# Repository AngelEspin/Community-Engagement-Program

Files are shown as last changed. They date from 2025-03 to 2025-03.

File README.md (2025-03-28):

# Community-Engagement-Program
This project involves the design and development of didactic prototypes aimed at helping children understand renewable energy concepts, specifically focusing on wind energy. The project includes:

Electronic Design: Design of PCB boards for educational prototypes.

Internal Wiring: Wire modeling using Autodesk Inventor.

Mechanical Design: Proper dimensioning and machining techniques to bring the prototypes to life.

Wind Energy System: The prototype includes a fan and generator to demonstrate wind energy.

The goal of this project is to create hands-on tools for educational purposes, enabling a better understanding of renewable energy systems in an interactive way.

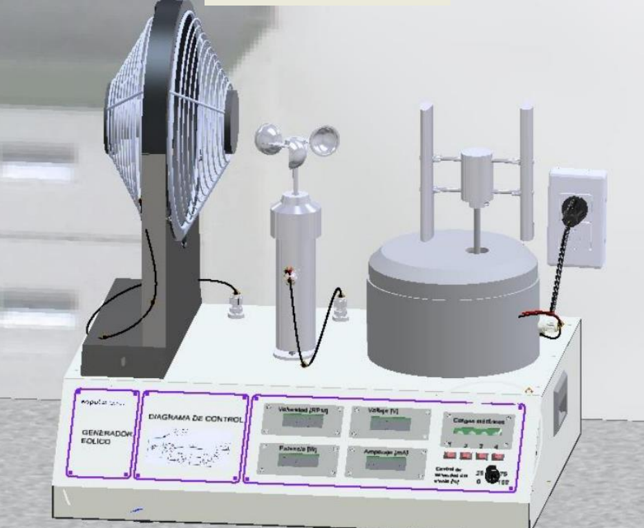
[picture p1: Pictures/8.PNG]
Final

## Mechanical Design
After taking the dimensions of the components into reality by using Inventor we need to specify to the mechanized laboratory exactly how this is supposed to be made, the fan is expected to be build by mechanizing it from a steel block, with the following dimensions:
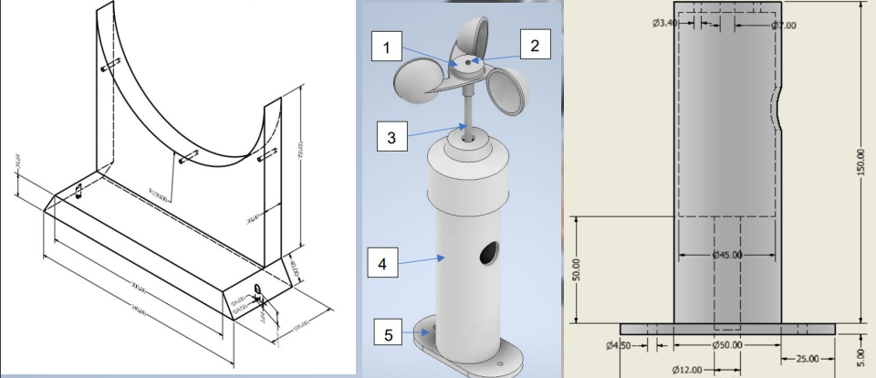
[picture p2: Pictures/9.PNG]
Mecanizado

## PCB's design
The requirements for this didactic module were that it needs to show qualitified and visualized the amount of energy produced by the wind generator. In order to do so, we've created PCB's that contains 7 segments led arrays and little incandescent bulbs by making the corresponding PCB's as shown in:
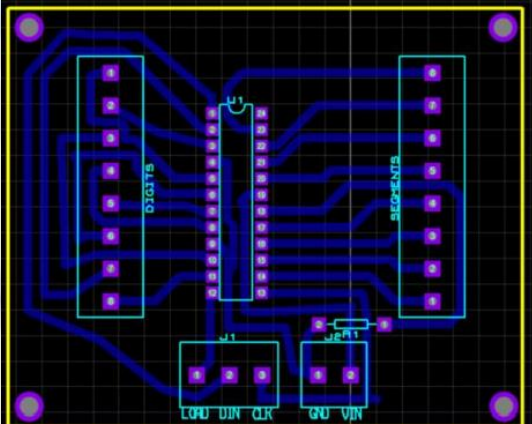
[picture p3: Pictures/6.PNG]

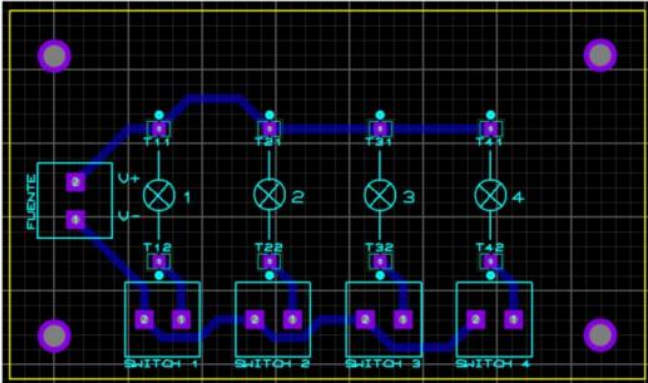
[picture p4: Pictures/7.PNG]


After making the PCB's usign proteus we export this into inventor by using a proteus option, and after verifying that it does fullfil the standards we incorporate this new modules to the existing 3D CAD design
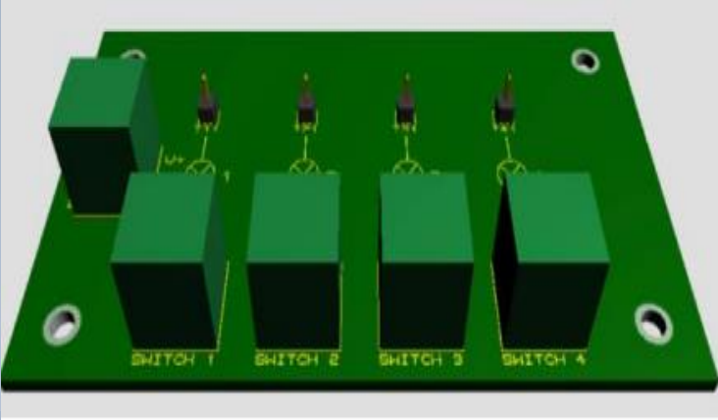
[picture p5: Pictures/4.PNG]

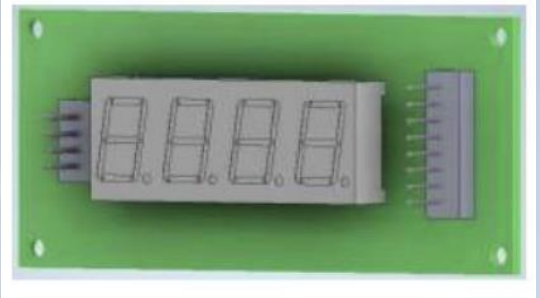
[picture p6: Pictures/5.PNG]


## Connection using Proteus modules and Inventor
After exporting the corresponing PCB's for each of the parts (the luminosity required to show the quantity of the wind energy and the displays showing the exact amount of energy consumed) the next step is to connect this new modules into the existing microcontrollers such as ATmega328P (Arduino Module), after succesfully connecting this components the next part is to make sure that the physical restrictions do not interfere with the connections, since the cables are numbered specifying the current that they can pass.
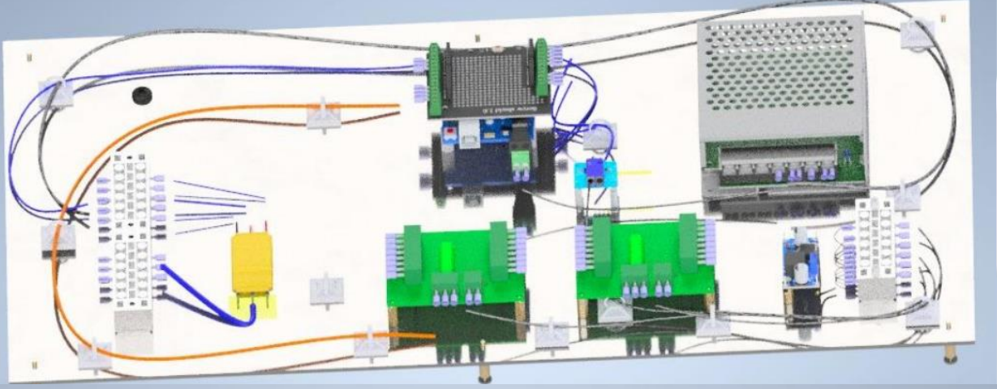
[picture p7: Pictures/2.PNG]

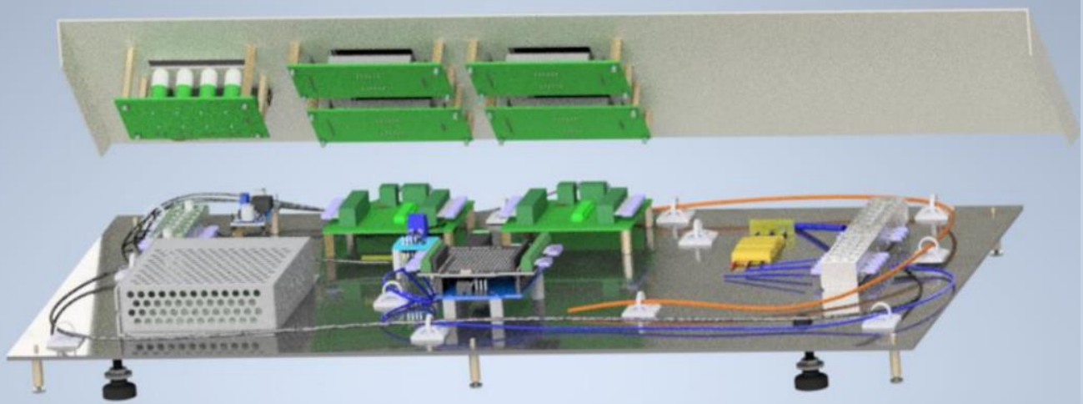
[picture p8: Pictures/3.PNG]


## Drawings (DWG) using Inventor
The mechanical design was used to verify the sustainability of the project and how realistic is to build this didactic equipment by following real life restrictions. After the process ended the final squematic looks like this:
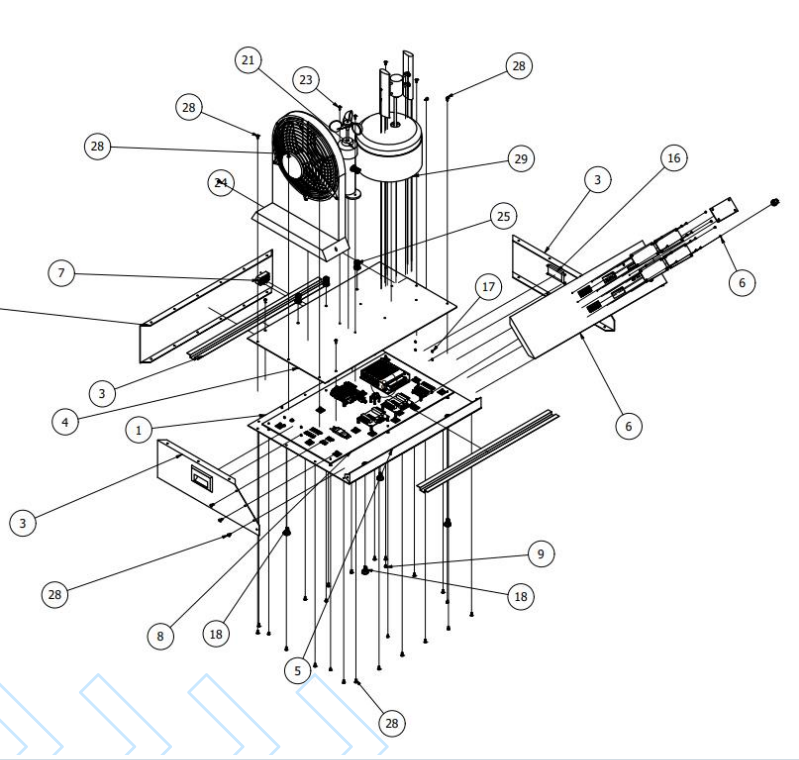
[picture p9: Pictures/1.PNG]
Poster


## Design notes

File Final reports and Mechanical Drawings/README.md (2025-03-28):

# Community-Engagement-Program
his project involves the design and development of didactic prototypes aimed at helping children understand renewable energy concepts, specifically focusing on wind energy. The project includes:  Electronic Design and Internal Wiring using Autodesk Inventor and Proteus.  Mechanical Design: Proper dimensioning and machining techniques.

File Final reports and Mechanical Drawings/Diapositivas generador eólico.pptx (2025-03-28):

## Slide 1

Desarrollo de Equipo didactivo para energía renovable eólica

En nuestro proyecto de ingeniería para el desarrollo de prototipos didácticos para formación educativa, el diseño de un generador de energía eólica

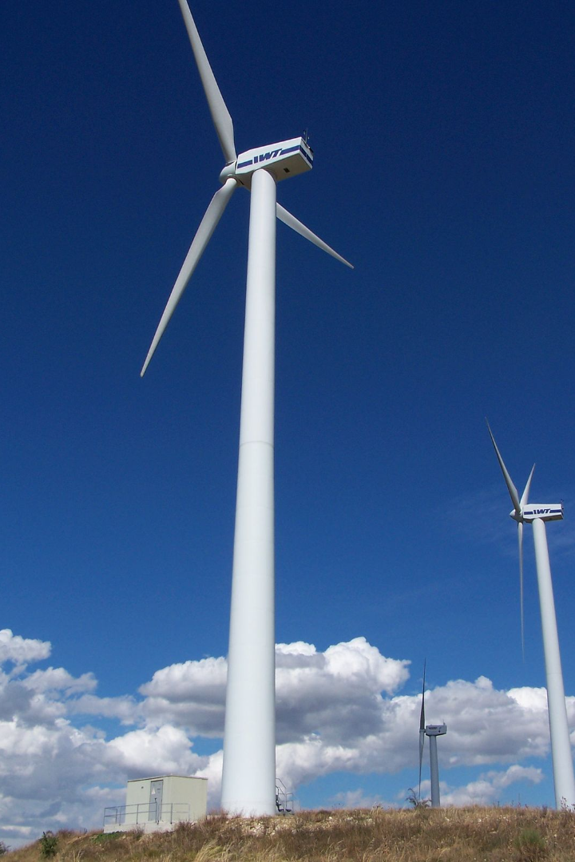
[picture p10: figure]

Andree Fonseca

Angel Espín

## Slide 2

La Energía Eólica

La energía eólica es la energía renovable obtenida a través del viento. Es una fuente de energía limpia, sostenible y no contaminante para el medio ambiente.

Definición

Se obtiene mediante aerogeneradores, que transforman la energía cinética del viento en energía mecánica y, posteriormente, en electricidad.

Funcionamiento

La energía eólica reduce el uso de combustibles fósiles y contribuye a disminuir la emisión de gases contaminantes a la atmósfera, contribuyendo al cuidado del medio ambiente.

La energía eólica se utiliza principalmente en la generación de electricidad, tanto para uso doméstico como industrial.

Beneficios

Aplicaciones

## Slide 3

Generador de Energía Eólica

Chasis de Generador

1

Sistema de Captura del Viento

Aspas montadas en el eje del motor que generan movimiento rotativo cuando el viento las golpea.

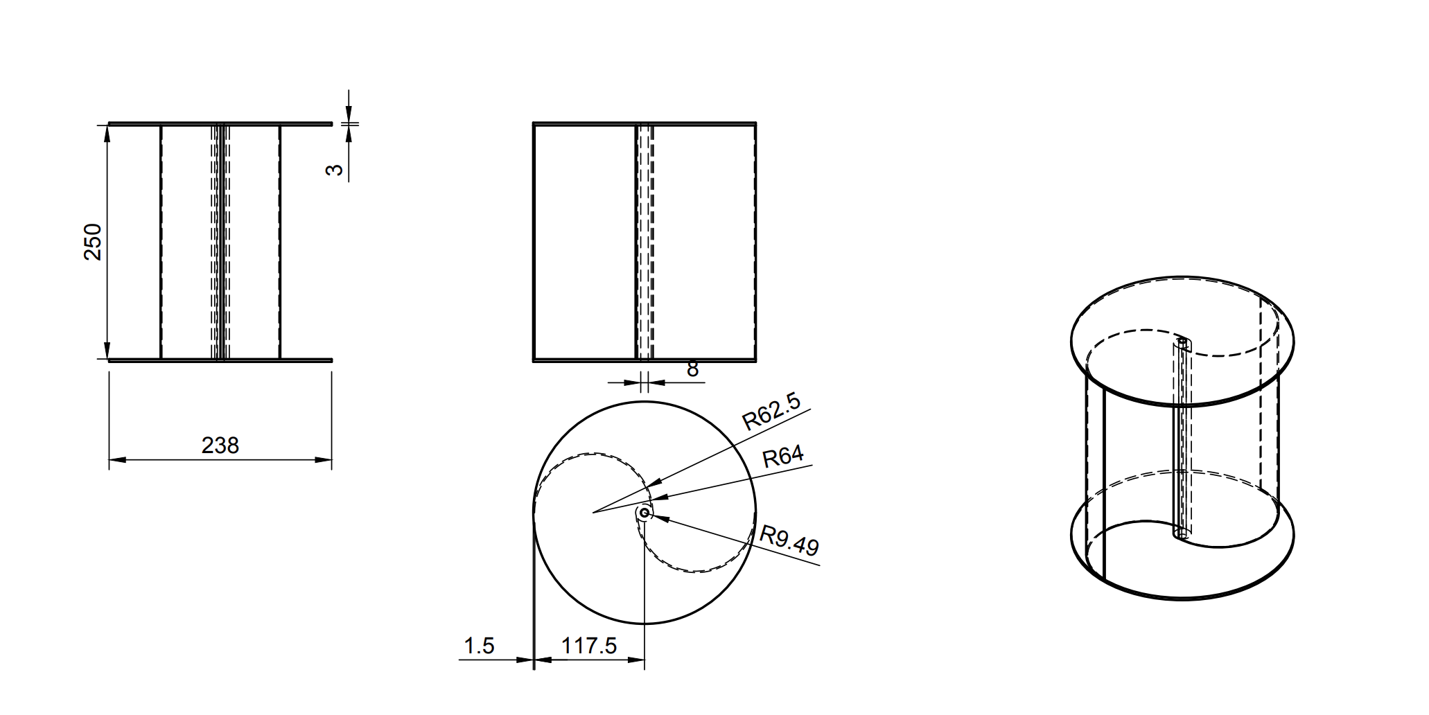
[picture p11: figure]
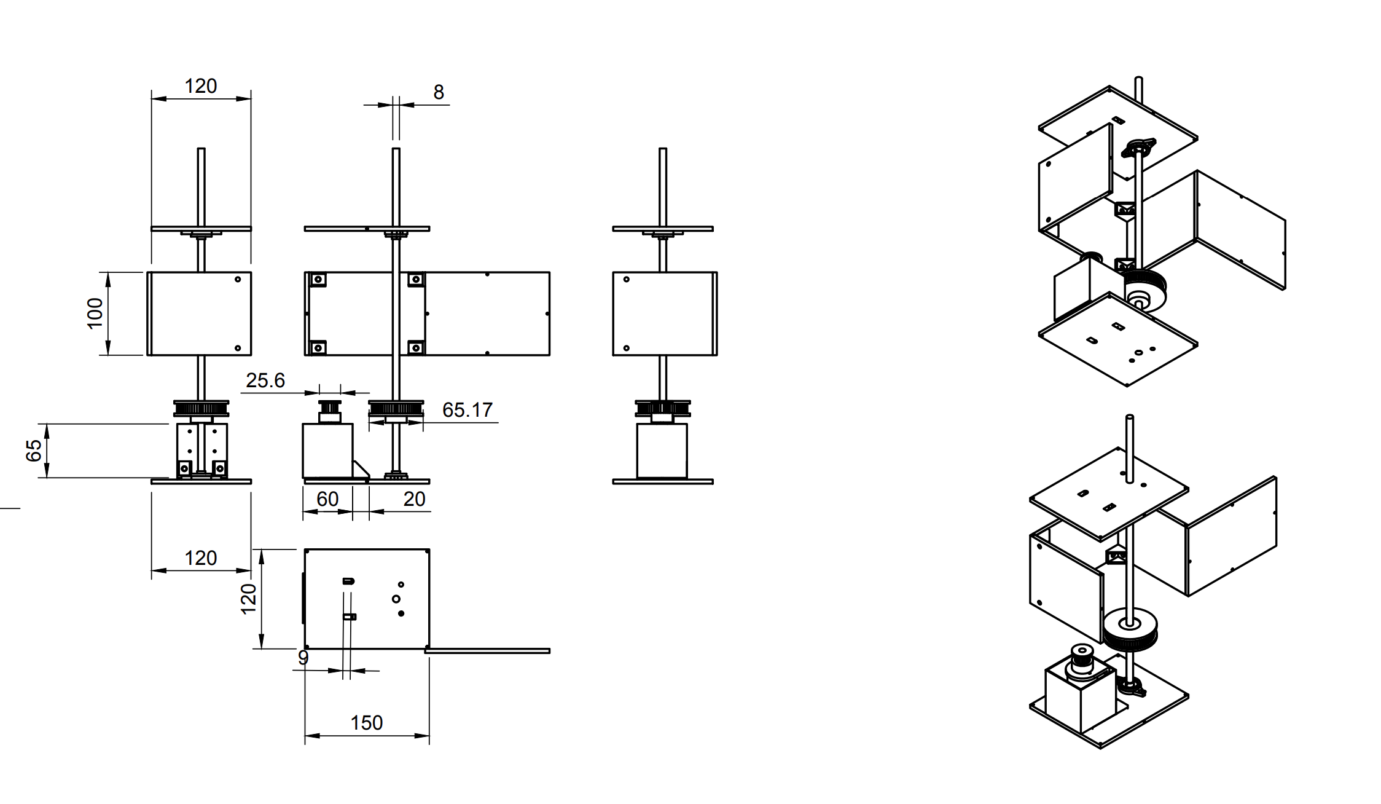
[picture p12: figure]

Sistema de Transmisión

Utiliza poleas dentadas para aumentar la velocidad de rotación y optimizar la conversión de energía cinética en electricidad.

2

3

Generación de Viento

Se emplea un motor para simular las condiciones de viento y evaluar el funcionamiento del generador.

Sistema Eléctrico con Medición de Parámetros

Incluye sensores para medir la velocidad del viento, la potencia generada, el voltaje y el amperaje. También se conectan focos incandescentes como cargas eléctricas.

4

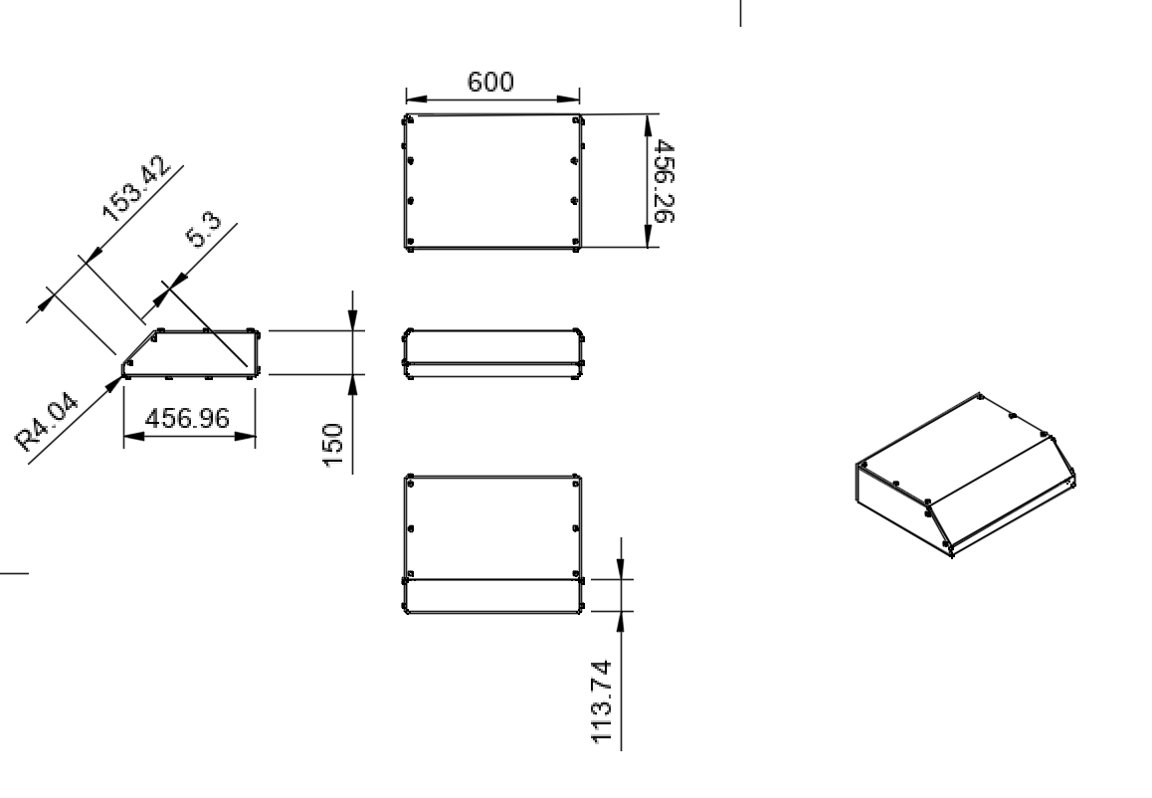
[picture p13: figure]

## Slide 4

Diseño conceptual

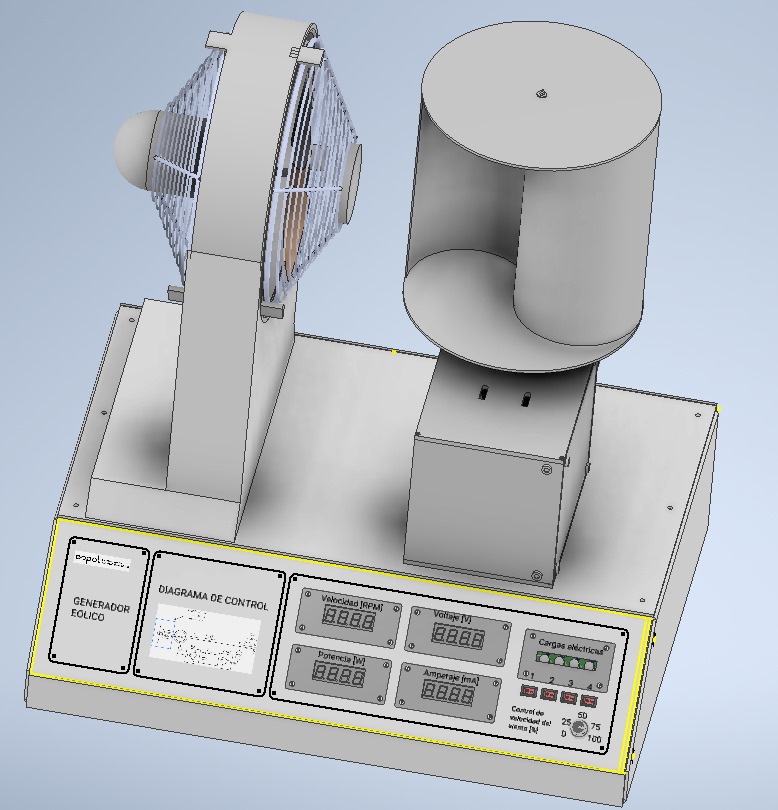
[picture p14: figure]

Partes

1. Generacion de viento
2. Recolector de energía de viento
3. Chasis
4. Panel frontal
5. Esquema electrico

1

5

2

3

4

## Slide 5

Dimensiones del prototipo

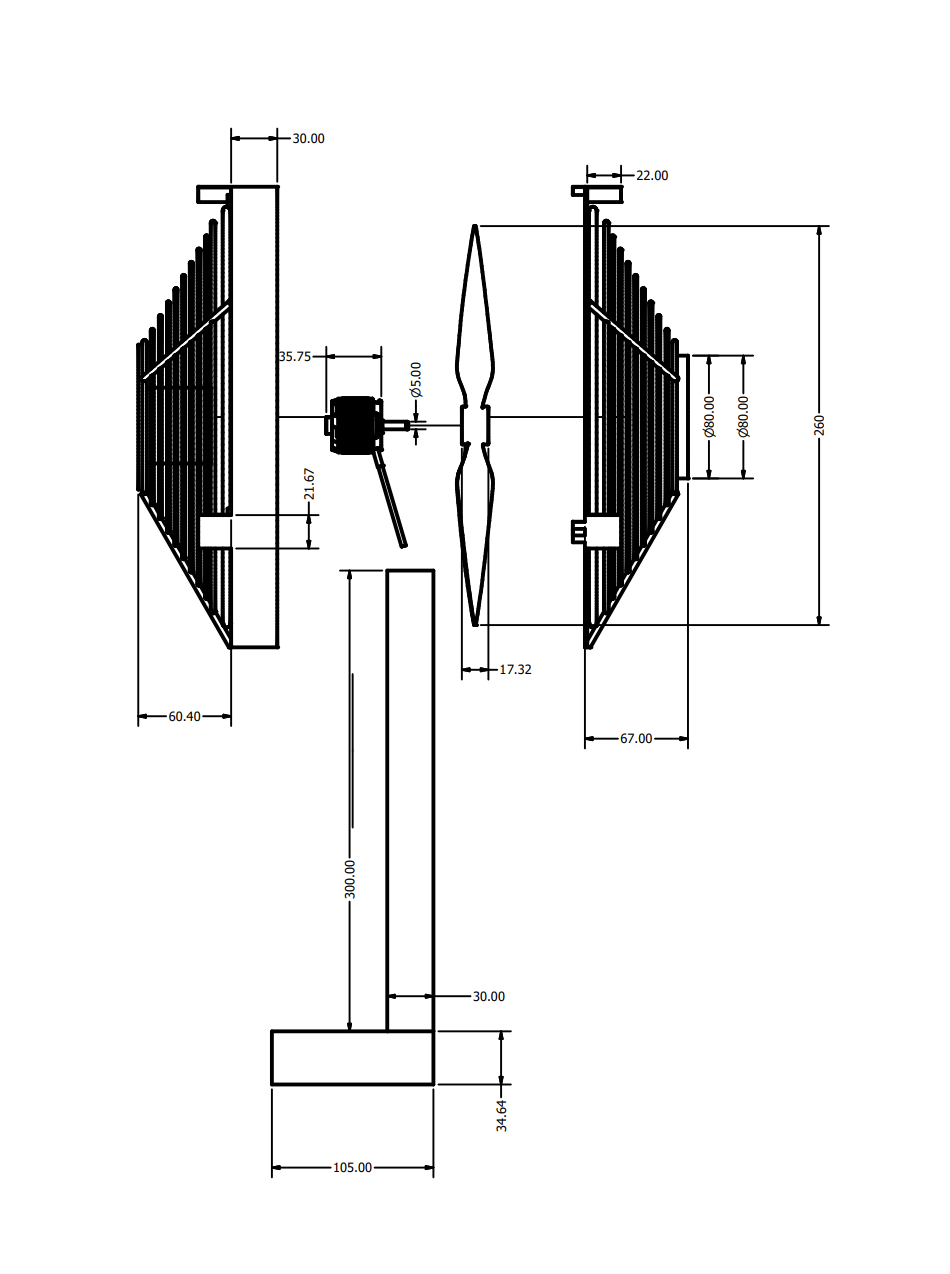
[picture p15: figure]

Partes

1. Generación de viento (127.40 X 150 X 430)(mm3)
2. Recolector de energía de viento (150 X 120 X 354)(mm3)
3. Chasis (600 X 256.26 X 150)(mm3)
4. Panel frontal (600 X 153.42x 5)(mm2)
5. Esquema eléctrico(200x100x27)(mm3)

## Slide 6

Dimensiones del prototipo

Dimension
Final

600 X 256.26 X 430 mm3

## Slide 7

Redes Eléctricas y Mediciones del Sistema

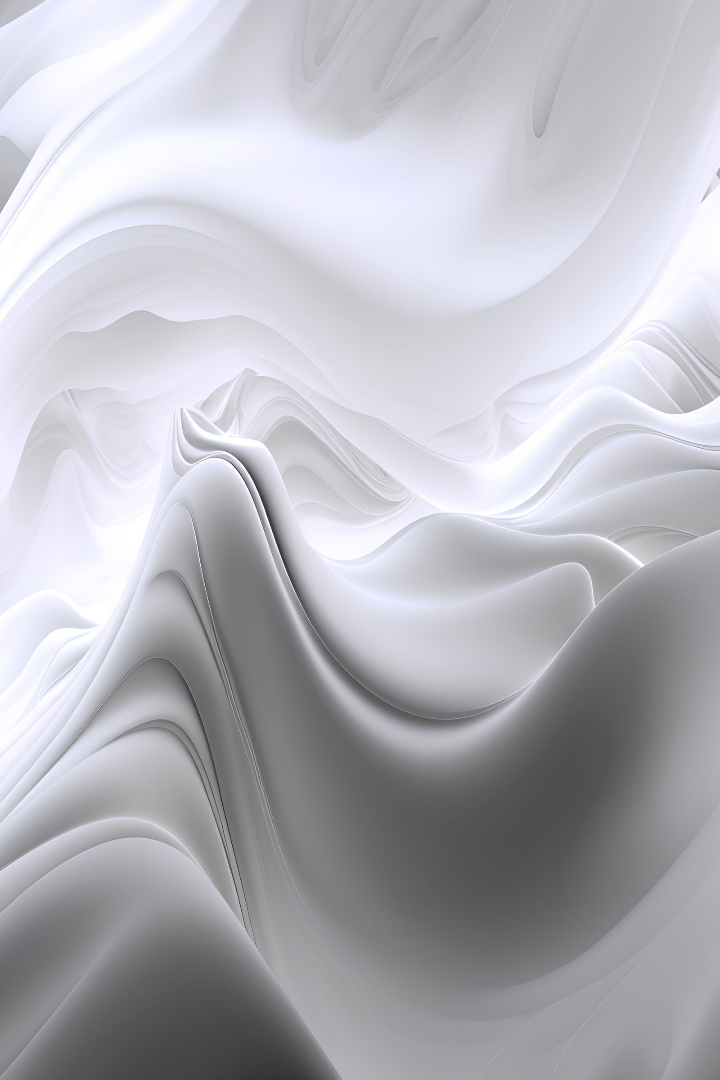
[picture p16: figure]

1

Requisitos del Sistema

Se deben definir los requisitos del sistema, como voltaje, corriente, tipo de sensores, etc.

2

Componentes Necesarios

Se deben seleccionar los componentes necesarios, como fuentes de alimentación DC, cables, sensores, controladores y equipos de medición.

3

Integración de Sistemas de Medición

Se deben instalar sensores y transductores adecuados para medir el funcionamiento del generador.

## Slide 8

Redes Eléctricas y Mediciones del Sistema

1

Requisitos del Sistema

Se deben definir los requisitos del sistema, como voltaje, corriente, tipo de sensores, etc.

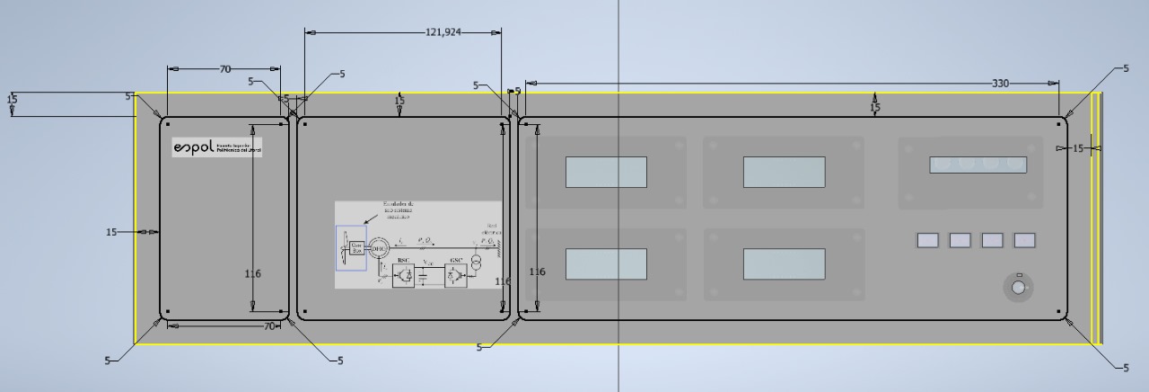
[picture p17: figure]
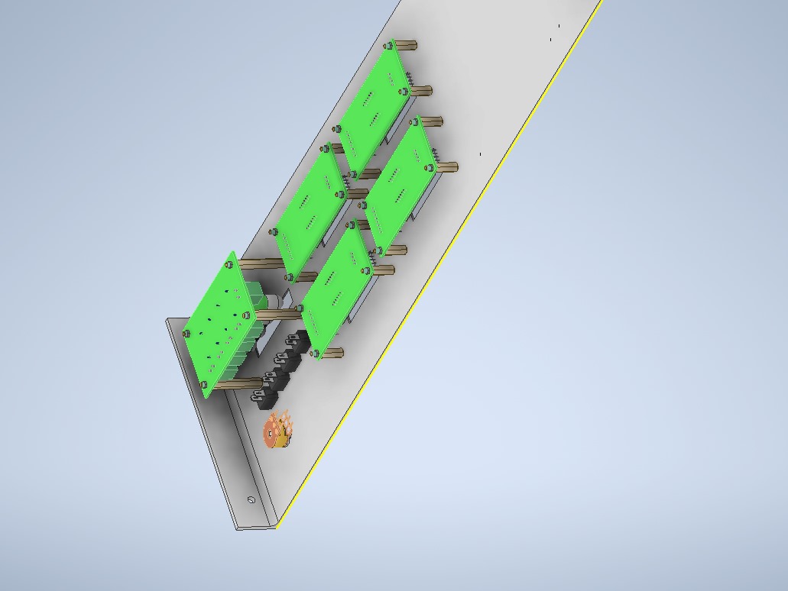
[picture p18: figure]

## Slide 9

Redes Eléctricas y Mediciones del Sistema

2

Componentes Necesarios

Se deben seleccionar los componentes necesarios, como fuentes de alimentación DC, cables, sensores, controladores y equipos de medición.

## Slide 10

Redes Eléctricas y Mediciones del Sistema

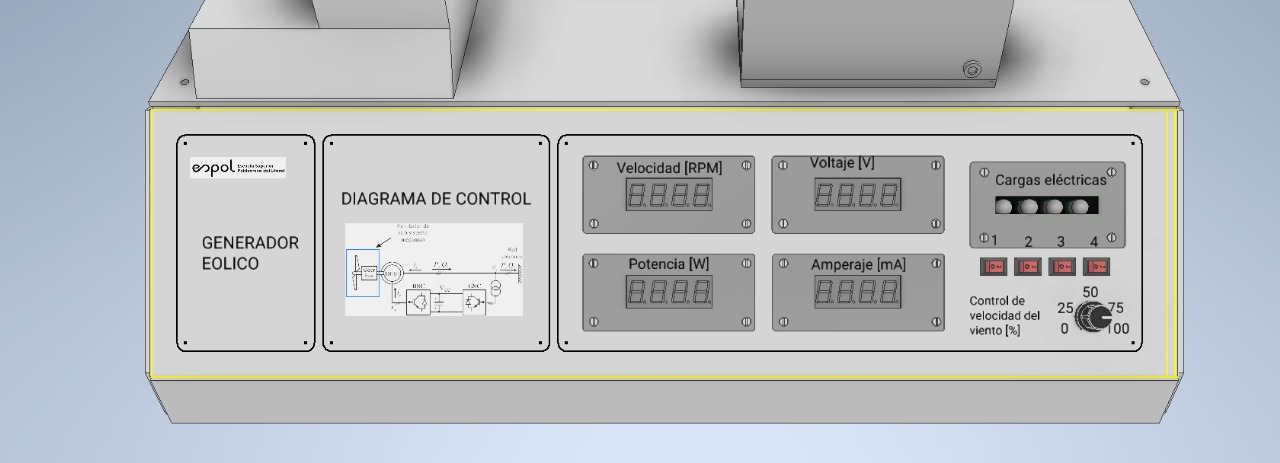
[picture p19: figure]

3

Integración de Sistemas de Medición

Se deben instalar sensores y transductores adecuados para medir el funcionamiento del generador.

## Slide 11

Diseño de Alimentación y Distribución de Energía

Fuente de Alimentación DC

Se debe elegir la fuente de alimentación DC adecuada que cumpla con los requisitos de voltaje y corriente.

Sistema de Distribución de Energía

Se debe diseñar una distribución de energía eficiente que incluya reguladores de voltaje, interruptores y fusibles.

Cableado y Conexiones

Se deben seleccionar cables adecuados y realizar las conexiones siguiendo las polaridades correctas.

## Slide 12

Diseño de Alimentación y Distribución de Energía

Fuente de Alimentación DC

INPUT 110-120 VAC-5A
OUTPUT 12VDC-10A

Sistema de Distribución de Energía

Reguladores
STEP-DOWN 12 a 5VDC
Integrados de componentes de medición

Cableado y Conexiones

AWG 16 (Generador de viento)
AWG 20(Sistema general)

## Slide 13

Armado y Ajustes

Aje de las Láminas de Acrílico

Coloca las láminas de acrílico sobre la estructura y asegúrate de que estén niveladas y alineadas correctamente. Usa clips o adhesivos adecuados para sujetarlas en su lugar.

Sistema de Transmisión de Potencia de las Aspas al Motor

Se debe garantizar una transmisión de potencia eficiente desde las aspas hasta el motor que produce la electricidad.

Acabado y Estética

Revisa la base para asegurarte de que esté nivelada y que las láminas de acrílico estén seguras. Realiza ajustes si es necesario para lograr estabilidad y estética.

Limpieza y Mantenimiento

Limpia la base y las láminas de acrílico con un paño suave y agua jabonosa si es necesario. Mantén la base limpia y realiza el mantenimiento regularmente para prolongar su vida útil.

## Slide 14

SISTEMA/PARAMETRO | RPM | Velocidad | Voltaje | Amperaje | Aspas | focos
Generador de viento | --- | 5 – 8 m/s | 0-10V | 6.6A | Drone sentido invertido | ------
Generador de electrico | 0-2800 | ----- | 0-12V | 0.8A | Savonius | 4

Condiciones de operación generador

~~10 VATIOS

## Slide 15

Precio del equipo

SISTEMA/PARAMETRO | USD
Generador de viento | 70.00
Generador de electrico | 42.50
Chasis | 72.40
Componentes electricos | 80.32
Helices | 30.00

295.22 USD

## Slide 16

Nuestro proyecto de prototipos didácticos para formación educativa se enfocó en el diseño de un generador de energía eólica que tiene como objetivos construir una maqueta con molinos de viento que giren y generen electricidad simulada, y utilizar este generador como herramienta educativa para enseñar sobre la importancia de la energía eólica y su contribución al cuidado del medio ambiente.

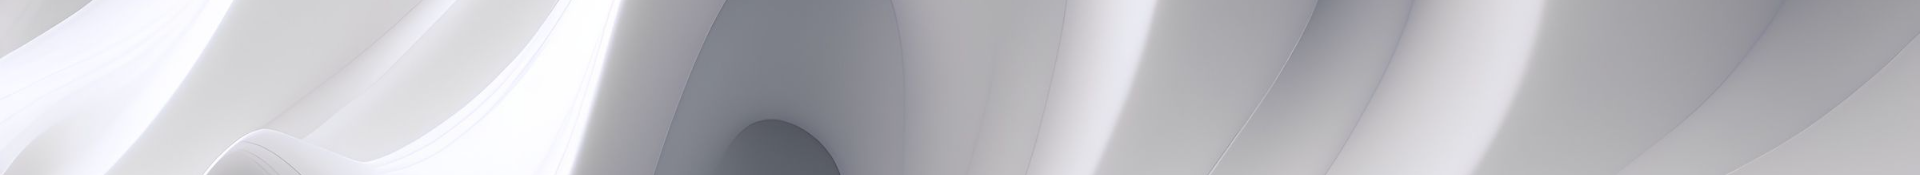
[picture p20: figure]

Conclusiones

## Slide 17

Agradecimientos

Agradecemos al Programa de Vinculación de la FIMCP (2023-2027) por el apoyo en este proyecto, y al Tutor Zamora Olea Geancarlos por su guía y orientación en el diseño y construcción del generador de energía eólica.

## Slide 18

Link del video

https://youtu.be/pXkPgLcf1LA

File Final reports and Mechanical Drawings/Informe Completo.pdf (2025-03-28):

PRÁCTICAS DE SERVICIO COMUNITARIO

PROYECTO:

INGENIERÍA PARA EL DESARROLLO DE PROTOTIPOS DIDÁCTICOS

PARA FORMACIÓN EDUCATIVA

PROGRAMA:

PROGRAMA DE VINCULACIÓN DE LA FIMCP (2023-2027)

TUTOR:

ZAMORA OLEA GEANCARLOS

ESTUDIANTES:

ESPIN LUMBANO ANGEL JOSUE

angelumb@espol.edu.ec

FONSECA MEDINA ANDRÉE GABRIEL

andgafon@espol.edu.ec

## Contenido

Pasos para pintar sobre acero A36 con esmalte sintético Proanox:.......21

### 1. RESUMEN

A medida que se continúan desarrollando tecnologías y promoviendo políticas favorables, las energías renovables se están convirtiendo en la columna vertebral de un futuro energético sostenible. El propósito de este proyecto es permitir la creación de equipos didácticos y amigables destinados a estudiantes de diversos niveles de educación. En este informe se analizan las ventajas, desventajas, oportunidades y áreas de mejora de un generador eólico vertical didáctico.

### 2. INTRODUCCION

Las energías renovables han adquirido una creciente relevancia a nivel mundial gracias a su impacto positivo en el medio ambiente y su capacidad para abastecer las necesidades energéticas de forma sostenible. Estas fuentes energéticas se derivan de recursos naturales inagotables o de rápida regeneración, incluyendo la energía solar, eólica, hidroeléctrica, geotérmica y la biomasa.

A diferencia de los combustibles fósiles, cuya extracción y quema generan emisiones de gases de efecto invernadero y contribuyen al cambio climático, las energías renovables no emiten gases contaminantes durante su funcionamiento. Esto las convierte en una alternativa limpia y respetuosa con el medio ambiente, ayudando a reducir la contaminación del aire y mitigar el calentamiento global.

Además de su beneficio ambiental, las energías renovables también tienen un impacto positivo en la economía global. La transición hacia fuentes de energía renovable ha generado la creación de nuevos empleos en el sector, desde la fabricación, instalación de paneles solares y aerogeneradores hasta la operación, mantenimiento de parques eólicos y plantas solares. Estas inversiones en energías renovables también promueven la independencia energética, ya que reducen la dependencia de los combustibles fósiles importados.

En términos de acceso a la energía, las fuentes renovables pueden proporcionar soluciones a comunidades rurales o remotas que no tienen acceso a la red eléctrica convencional. La energía solar, por ejemplo, puede aprovecharse a través de paneles solares individuales o sistemas de microrredes, llevando electricidad a áreas que anteriormente dependían de fuentes contaminantes o que carecían de energía por completo.

Energía eólica
Se define a la energía eólica como aquella energía generada por el viento. Es una forma de energía renovable que aprovecha la fuerza cinética del viento para convertirla en energía eléctrica o mecánica. Se obtiene mediante la utilización de aerogeneradores, que son grandes estructuras equipadas con hélices o palas que giran cuando son impulsadas por el viento. La energía cinética del viento se transforma en energía mecánica al hacer girar las hélices, y luego esta energía mecánica se convierte en electricidad mediante un generador. La energía eólica es una fuente limpia y sostenible de energía que no produce emisiones de gases de efecto invernadero ni contribuye al calentamiento global.

En el proyecto de diseño de un generador de energía eólica, el objetivo principal es crear una representación visual que muestre cómo se puede generar electricidad a partir del flujo del viento. Para lograr esto, se plantearon dos objetivos específicos:

Diseño Funcional: El primer objetivo se enfoca en construir una maqueta que incluya molinos de viento que realmente giren y generen electricidad simulada cuando el viento los mueva. Esto ayudará a las personas a comprender de manera práctica cómo funciona la energía eólica.

Educación Ambiental: El segundo objetivo es utilizar un equipo como una herramienta educativa para enseñar a las personas sobre la importancia de la energía eólica y cómo contribuye a cuidar nuestro entorno. Queremos crear materiales y presentaciones informativas que expliquen cómo la energía eólica es una fuente de energía limpia y cómo puede ayudar a reducir la contaminación y el cambio climático. Nuestra meta final es concienciar a la comunidad sobre la importancia de las energías renovables.

### 3. OBJETIVOS

Objetivo general
Diseñar un equipo didáctico de energía eólica con el propósito de demostrar su uso e importancia en la generación de energía sostenible

Objetivos específicos
- Evaluar el estado de los prototipos de energía eólica actuales.
- Desarrollar un módulo didáctico de energía eólica como producto final.
- Realizar el diseño mecánico, electrónico y de control del módulo de energía eólica didáctico y mostrar el proceso de construcción mediante planos e instrucciones de diseño.
- Innovar en el desarrollo de un módulo de energía eólica didáctico como una nueva forma de enseñanza sobre el uso de energías renovables.

### 4. DISEÑO CONCEPTUAL

Un módulo didáctico de generación de energía eólica es un dispositivo diseñado para capturar la energía cinética del viento y convertirla en energía mecánica o eléctrica de manera educativa y práctica. Este módulo tiene como objetivo principal enseñar los principios fundamentales de la generación de energía eólica y su importancia en la producción de energía sostenible.

La estructura básica del módulo didáctico de generación de energía eólica consta de varios componentes esenciales:

- Aspas del Ventilador: Estas son las partes del módulo expuestas directamente al viento y diseñadas para capturar eficientemente la energía cinética del mismo. Las aspas están conectadas al generador y suelen estar hechas de materiales resistentes y livianos. (Ver Ilustración 5 Generador de eje vertical o Ilustración 6 Aerogenerador con eje horizontal, son las dos posibilidades)
- Generador: Detrás de las aspas, se encuentra un generador que convierte la energía mecánica generada por el giro de las aspas en energía eléctrica. Este generador puede ser un generador de corriente continua (DC) utilizado con fines educativos.

Ilustración 1 Motor como generador

- Anemómetro: El módulo está equipado con un anemómetro que mide la velocidad del viento. Esto permite a los estudiantes comprender la relación entre la velocidad del viento y la generación de energía eólica.

Ilustración 2 Anemómetro

- Aumento de Velocidad: Para fines educativos, se incorpora un mecanismo que permite aumentar o disminuir la velocidad del viento que llega a las aspas. Esto ayuda a los estudiantes a experimentar cómo diferentes velocidades de viento afectan la generación de energía.

Ilustración 3 Control de velocidad

- Mecanismo de Transmisión de Potencia: El generador está conectado a un mecanismo de transmisión de potencia que ilustra cómo la energía mecánica se convierte en energía eléctrica. Este mecanismo es visible para que los estudiantes puedan observar su funcionamiento.

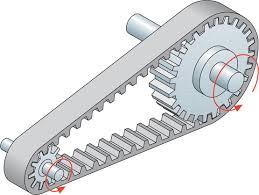
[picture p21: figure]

Ilustración 4 Mecanismo de transmisión de potencia

Dichos componentes serán los que se utilizarán para el diseño final del módulo. Sin embargo, respecto a las aspas del generador, se plantearon dos posibilidades, tener un eje vertical u horizontal.

Diseño Conceptual uno: Generador de Eje Vertical

En este diseño, se utiliza un generador de eje vertical con tres aspas aerodinámicas montadas en un eje central. Las aspas están conectadas a un sistema de poleas dentadas que aumenta la velocidad de rotación del eje del motor. Para simular el viento, un motor se coloca estratégicamente para generar un flujo de aire hacia las aspas. El sistema eléctrico incorpora sensores de velocidad del viento, potencia, voltaje y amperaje, junto con luces incandescentes como cargas eléctricas para visualizar la producción de electricidad.

Ilustración 5 Generador de eje vertical

- Diseño Conceptual dos: Aerogenerador de Eje Horizontal con Aspas

En este diseño, se utiliza un aerogenerador de eje horizontal con tres aspas largas y delgadas montadas en un eje horizontal. El viento natural impulsa las aspas, que están conectadas directamente a un generador eléctrico. Para complementar el viento natural y permitir pruebas controladas, se incorpora un motor que puede ajustar su velocidad para simular diferentes condiciones de viento. El sistema de medición eléctrica incluye sensores de velocidad del viento, potencia, voltaje y amperaje, así como luces incandescentes como cargas eléctricas para mostrar la generación de electricidad.

Ilustración 6 Aerogenerador con eje horizontal

- Propuesta de diseño innovador

Se planteó la implementación de una plataforma giratoria que permitiera alinear la dirección del ventilador con el viento en tiempo real. Además, se consideró la incorporación de una veleta para proporcionar una indicación visual de la dirección del viento.

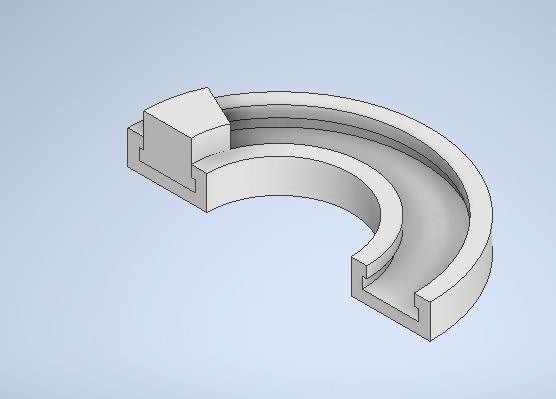
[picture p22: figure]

Ilustración 7 Base giratoria

Diseños del panel frontal
Se desarrollaron varios conceptos respecto al panel frontal del módulo eólico, los cuales son los siguientes:

Ilustración 8 Concepto inicial panel frontal

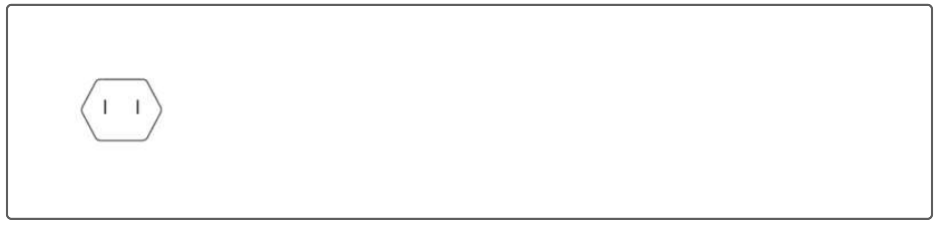
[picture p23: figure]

Ilustración 9 Concepto inicial panel posterior

Ilustración 10 Concepto general del panel frontal

Las partes importantes de este concepto general del panel frontal son las siguientes: logo, diagrama esquemático, nombres de las variables a medir, displays para indicar el valor, switch de apagado. Son importantes ya que se espera que el diseño sea visual y se entienda el propósito del módulo, además también se requiere que los displays sean lo suficientemente grandes para ver el cambio de las variables medidas.

Dichos conceptos iniciales sirvieron de base para poder crear el diseño preliminar del panel frontal, el cual fue el siguiente:

Ilustración 11 Medidas generales del panel frontal

Creación del prototipo con las dimensiones generales
El prototipo inicial del proyecto se fundamentó en la integración de cuatro componentes clave: un ventilador para simular la generación del viento, un anemómetro destinado a medir la velocidad del viento, un generador y una veleta. Además, se incluyeron diversas alternativas para la medición de las variables, como una tira de LED para representar visualmente la velocidad del viento, un display LCD para mostrar los valores de corriente, potencia y voltaje generados, así como componentes de control, como un potenciómetro para ajustar la velocidad del viento y un botón de encendido y apagado.

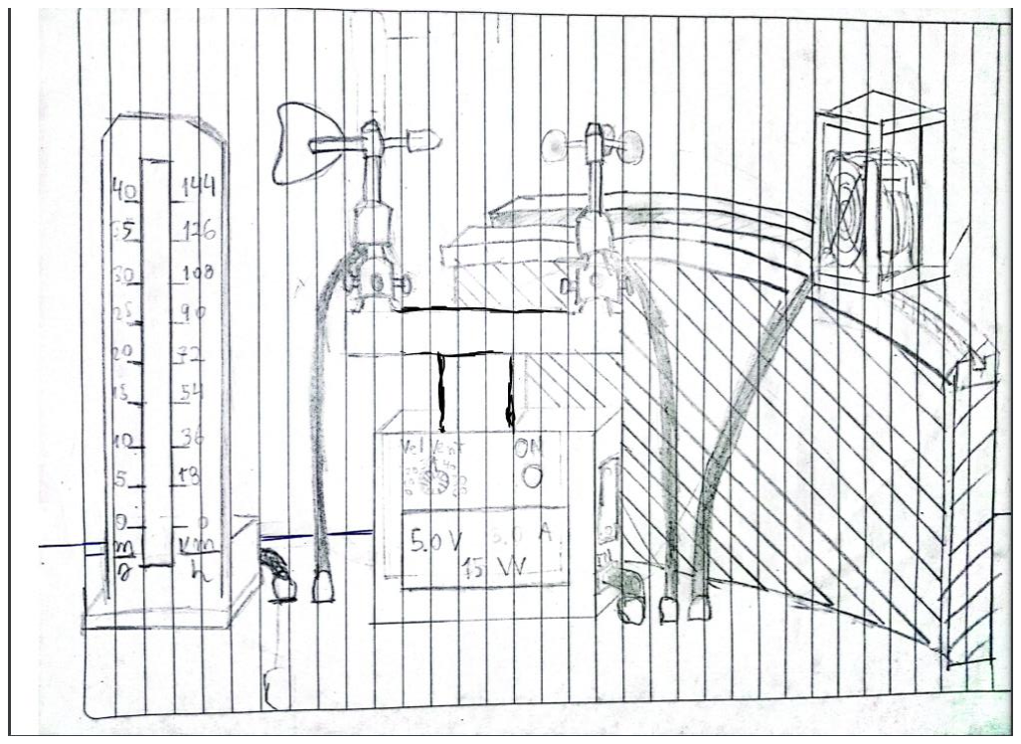
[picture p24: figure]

Ilustración 12 Prototipo del módulo eólico

Ilustración 13 Dimensiones generales del módulo eólico

Ilustración 14 CAD preliminar del prototipo

### 5. DESCRICPIÓN PROTOTIPO ACTUAL

El generador de energía eólica a pequeña escala consta de varias etapas clave para la captura y conversión de la energía cinética del viento en electricidad:

- Generación de Viento: Para simular las condiciones de viento, se emplea un motor sin escobillas o por sus siglas en inglés BLDC (Brushless DC Motor), en conjunto con unas aspas instaladas de forma invertida. Este motor produce una corriente de aire que imita las fuerzas del viento, lo que permite evaluar el funcionamiento del generador en diferentes velocidades del viento.
- Sistema de Captura del Viento (Aspas y Eje del Motor): En la primera etapa, aspas de manera aerodinámica se montan en el eje del motor. Cuando el viento incide sobre estas aspas, generan un movimiento rotativo en el eje.
- Sistema de Transmisión (Poleas Dentadas): Para aprovechar eficazmente el movimiento rotativo del eje, se utiliza un sistema de poleas dentadas. Esto permite aumentar la velocidad de rotación del generador, optimizando la conversión de la energía cinética en electricidad.
- Sistema de eléctrico con medición de parámetros: El sistema eléctrico incluye sensores para medir diversas variables. Estos sensores registran la velocidad del viento, la potencia generada, el voltaje y el amperaje. También el generador permite la conexión de focos incandescentes de 5V como cargas eléctricas para ilustrar la producción de electricidad.

En resumen, este generador de energía eólica en miniatura está compuesto por componentes esenciales para la captura, transmisión y conversión de la energía del viento en electricidad. También cuenta con un sistema de medición eléctrica que proporciona datos en tiempo real para evaluar su rendimiento.

Ilustración 15 Módulo didáctico de generación de energía eólica

### 6. PROCESO DE DESARROLLO

Materiales mecánicos:

### 5.1 Diseño mecánico:

Para esta sección se evaluará la viabilidad de construir un módulo en base a dos diseños conceptuales de aerogenerador, el diseño conceptual 1 es representado por la Ilustración 5 Generador de eje vertical, mientras que el diseño conceptual 2 se visualiza en la Ilustración 6 Aerogenerador con eje horizontal

5.1.1 Selección de desarrollo de aspas:
El diseño conceptual 1, que utiliza un generador de eje vertical con aspas y un motor para simular el viento, es menos complejo de construir que el diseño conceptual 2, que emplea un aerogenerador de eje horizontal. A continuación, se detallan las razones que sustentan la afirmación:
- Simplicidad del Diseño Mecánico:
Item | Componentes | Descripción | Cantidad | Precio ($) | Precio Total
1 | Plancha de hierro negro | | 1 | $ 30.00 | $ 30.00
2 | Rodamiento plano cuadrado | 10cm x10cm | 1 | $ 10.00 | $ 10.00
3 | Punteros de reloj | | 3 | $ 8.00 | $ 24.00
4 | Pernos pequeños | 5mm | 75 | $ 0.10 | $ 7.50
5 | Tuercas | 5mm | 75 | $ 0.10 | $ 7.50
6 | Arandelas planas | 5mm | 75 | $ 0.10 | $ 7.50
7 | Tuerca mariposa | 5mm | 1 | $ 0.75 | $ 0.75
8 | Topes de caucho cilíndricos | 5mm | 2 | $ 0.50 | $ 1.00
9 | Perno largo | 20mm x 5mm | 1 | $ 1.50 | $ 1.50
10 | Pintura | esmalte sintético | 750 ml | $ 23.00 | $ 23.00
11 | Lijas para pulir | Gruesas y finas | 1 | $ 5.00 | $ 5.00
12 | Electrodos | 6013 o 6011 | 1 lb | $ 20.00 | $ 20.00
13 | Bases de cauchos (soporte) | 5mm | 4 | $ 2.50 | $ 10.00
14 | Viga Omega | 35x50x20x2 mm | 1 | $ 25.00 | $ 25.00
15 | Manijas | | 1 | $ 5.00 | $ 5.00
16 | Planchas de Hierro | Preferible buscar en los talleres de mantenimiento que sean placas de unos 3 o 4mm de espesor para la base que soportará la estructura del brazo, caso contrario comprar en una chatarrería. Dimensiones aproximadas de 50x50cm. | 1 | $ 5.00 | $ 5.00
17 | Acrílico transparente | 50 x 50 cm | 1 | $ 11.23 | $ 11.23
| | | | TOTAL | $193.98

En el diseño 1, el eje vertical es más sencillo de fabricar y montar que un sistema de eje horizontal. No se requiere una estructura de torre alta para elevar el generador y las aspas.

- Menos Componentes en Movimiento:

El diseño 1 implica menos componentes móviles, ya que las aspas giran alrededor de un eje vertical y no requieren un mecanismo de orientación complicado para seguir el viento. Esto reduce la complejidad y el potencial de problemas mecánicos.

- Facilidad de Ajuste del Motor

En el diseño 1, el motor se utiliza para simular el viento y puede ajustarse fácilmente para variar la velocidad del viento simulado. Esto permite una experimentación más controlada y sencilla en comparación con el diseño 2, que depende de la dirección natural del viento.

- Menor Tamaño y Espacio Requerido:

El diseño 1 ocupa menos espacio físico debido a la disposición vertical de las aspas y el generador. Esto lo hace más adecuado para entornos con espacio limitado y facilita su transporte y almacenamiento.

- Menos Requisitos de Mantenimiento:

Debido a su simplicidad y menos componentes en movimiento, el diseño 1 tiende a requerir menos mantenimiento y es más duradero en el tiempo.

Dado a su simplicidad mecánica, menor cantidad de componentes móviles y la posibilidad de controlar la velocidad del viento simulado de manera precisa. Esto lo convierte en una opción más asequible y accesible para propósitos educativos y experimentales.

Ilustración 16 Aspas tipo Savonius

Ilustración 17 Aspas tipo Darrieus

Ilustración 18 Aspas tipo H

Metodología:

En esta sección se expondrán los pasos generales que deben seguirse en el proyecto de desarrollo de un módulo didáctico de enseñanza basado en la energía eólica, abarcando el período desde 2023 hasta 2027. No obstante, en el presente período se llevará a cabo únicamente la fase de diseño del módulo.

1. Requisitos del Diseño
- Especificaciones del Generador: En esta fase, se analizarán las especificaciones del generador eléctrico, incluyendo la potencia nominal, la velocidad de rotación y la tensión de operación. Estos parámetros proporcionarán las pautas necesarias para el diseño de las aspas.
- Velocidad del Viento Promedio: Se llevará a cabo una evaluación de la velocidad promedio del viento en el emplazamiento donde se instalará el sistema de generación eólica. Este factor influirá significativamente en el diseño de las aspas.
2. Diseño de Aspas Darrieus-Savonius
- Longitud de las Aspas (Darrieus): Mediante cálculos basados en la velocidad del viento, la potencia deseada y el radio del rotor, se determinará la longitud adecuada de las aspas Darrieus, teniendo en cuenta su curvatura y montaje vertical.
- Diseño de Aspas Savonius: Se establecerán las dimensiones apropiadas de las aspas Savonius en función de la velocidad del viento y la potencia deseada. Las aspas Savonius son semicirculares y se instalan de manera horizontal.
3. Materiales y Construcción
- Materiales de las Aspas: Se llevará a cabo la selección de los materiales más idóneos para la construcción de las aspas, considerando opciones como fibra de vidrio, aluminio y otros materiales compuestos. La durabilidad y la resistencia a la corrosión serán factores clave en esta elección.
4. Diseño Aerodinámico
- Perfil Aerodinámico: Se realizará el diseño del perfil aerodinámico de las aspas con el objetivo de maximizar la eficiencia y minimizar la resistencia al viento. Esto implicará definir la forma y la curvatura adecuadas para las aspas.
- Ángulo de Ataque: Se calculará el ángulo de ataque óptimo para las aspas en función de la velocidad del viento y la geometría del rotor.
5. Fabricación y Montaje
- Fabricación de las Aspas: Las aspas se construirán de acuerdo con las especificaciones de diseño utilizando técnicas apropiadas de fabricación, como el moldeo por inyección o la fabricación manual.

- Montaje: Las aspas se instalarán en el rotor o en el sistema
Darrieus-Savonius de | manera | que | estén | perfectamente
equilibradas y alineadas.
6. Pruebas y Optimización
- Pruebas de Rendimiento: Se llevarán a cabo pruebas de rendimiento en condiciones reales de viento para verificar que las aspas generen la potencia esperada.
- Ajustes: Si es necesario, se realizarán ajustes en el diseño o la geometría de las aspas para optimizar la eficiencia y el rendimiento del sistema.
7. Mantenimiento y Monitoreo
- Mantenimiento: Se establecerá un programa de mantenimiento periódico para inspeccionar y mantener las aspas en óptimo estado de funcionamiento.
- Monitoreo: Se implementarán sistemas de monitoreo para supervisar de forma continua el rendimiento de las aspas y detectar cualquier problema o desgaste prematuro.

### 5.1.2 Base del equipo

Metodología:

En cuanto al proceso de construcción de la base del equipo, la metodología empleada es la siguiente:

1. Diseño y Planificación: Antes de comenzar la fabricación, se lleva a cabo una planificación detallada que incluye el diseño de las dimensiones de la base. Se consideran las dimensiones de las láminas de acrílico y cualquier carga que deba soportar.
2. Corte de los Tubos o Barras: Los tubos o barras se cortan según las dimensiones especificadas en el diseño. Se realiza una medición precisa y se marcan los puntos de corte antes de proceder con la operación.
3. Montaje de la Estructura: La estructura se ensambla utilizando tornillos, tuercas y arandelas. El proceso de montaje se inicia desde la parte inferior, y se verifica que la estructura esté nivelada utilizando un nivel.
4. Preparación de las Láminas de Acrílico: Se miden y marcan las láminas de acrílico de acuerdo con las dimensiones establecidas en el diseño. Posteriormente, se cortan las láminas de acrílico con precisión, utilizando una sierra o cortador de vidrio para lograr cortes limpios y rectos.
5. Montaje de las Láminas de Acrílico: Las láminas de acrílico se colocan sobre la estructura y se asegura que estén niveladas y alineadas correctamente. Para sujetarlas en su lugar, se utilizan clips o adhesivos adecuados.
6. Acabado y Ajustes: Se realiza una revisión exhaustiva de la base para garantizar que esté nivelada y que las láminas de acrílico estén correctamente aseguradas. Se efectúan ajustes si es necesario para lograr estabilidad y un acabado estético.

7. Limpieza y Mantenimiento: Se recomienda llevar a cabo la limpieza de la base y las láminas de acrílico utilizando un paño suave y agua jabonosa si fuera necesario. Asimismo, se establece un programa de mantenimiento regular para prolongar la vida útil de la base.

### 5.1.3 Sistema de transmisión de potencia de las aspas al motor

Esta sección no es posible dimensionar directamente la relación inicial final de la transmisión por lo que se requiere que realizar pruebas del alcance que posee el motor.

Metodología:

1. Requisitos y Especificaciones

Se definirán los requisitos de la hélice, incluyendo diámetro, paso, velocidad de rotación deseada y sentido de giro (horario o antihorario). Además, se conocerán las especificaciones del motor, como velocidad nominal, potencia de salida y par motor máximo.

2. Selección de Materiales y Tipo de Engranajes
Se tomará la decisión sobre el tipo de engranajes a utilizar, ya sean rectos, helicoidales, cónicos u otros, según las necesidades del sistema y la disposición de los componentes. También se seleccionarán los materiales adecuados para los engranajes, priorizando la durabilidad y la reducción del desgaste.
3. Cálculos de Diseño
Se calculará la relación de transmisión necesaria para igualar la velocidad de la hélice a la velocidad nominal del motor utilizando la fórmula: Relación de transmisión = Velocidad del motor / Velocidad de la hélice. Se determinará el módulo y el paso de los engranajes, así como el número de dientes necesario para un funcionamiento óptimo.
4. Diseño de Ejes y Soportes
Se llevará a cabo el diseño de los ejes que sostendrán los engranajes y se conectarán al motor y la hélice. Se incorporarán soportes y rodamientos para garantizar una operación suave y minimizar la fricción en los ejes.
5. Simulación y Verificación
Se utilizará software de simulación de engranajes para verificar el diseño y evaluar su funcionamiento bajo diferentes condiciones de carga y velocidad. Si es posible, se realizarán pruebas en el mundo real para validar el rendimiento del sistema de engranajes.
6. Fabricación y Montaje
Se fabricarán los engranajes, ejes y otros componentes de acuerdo con las especificaciones de diseño. Luego, se ensamblará el sistema de engranajes asegurándose de que esté correctamente alineado y ajustado.
7. Pruebas y Ajustes Finales

Se realizarán pruebas de carga para asegurarse de que el sistema de engranajes funcione de acuerdo con las especificaciones bajo diversas condiciones. Se realizarán ajustes finos si es necesario para optimizar el rendimiento.
8. Mantenimiento y Monitoreo

Se establecerá un programa de mantenimiento regular para garantizar un funcionamiento confiable del sistema de engranajes y se realizará un seguimiento continuo de su desempeño.

### 5.2 Diseño eléctrico:

En el diseño eléctrico de este proyecto, se consideraron dispositivos de corriente continua para la sección de generación de energía eólica, porque facilitan el control de la velocidad del viento. Para ello, se evaluaron dos opciones principales en cuanto a motores y la electrónica de alimentación del sistema.

### 5.2.1 Motores DC como Generadores:

- Simplicidad de Conexión: Los motores de corriente continua pueden utilizarse directamente como generadores al conectarlos mecánicamente a las aspas. Esta facilidad de conexión simplifica su implementación en sistemas de generación eólica caseros.
- Control Preciso de la Velocidad: Los motores de corriente continua permiten un control preciso de la velocidad de rotación, lo cual es ventajoso para ajustar la generación de energía según las condiciones del viento. Esto puede mejorar la eficiencia en comparación con los motores de corriente alterna (CA) que operan a una frecuencia fija.
- Eficiencia en Bajas Velocidades de Viento: Los motores de corriente continua son capaces de generar electricidad incluso a bajas velocidades de viento, lo que los hace adecuados para áreas con vientos variables.
- Menor Requerimiento de Electrónica: Los motores de corriente continua tienden a requerir menos componentes electrónicos para la conversión de energía en comparación con los motores de corriente alterna, lo que puede simplificar el sistema.

### 5.2.2 Motores AC como Generadores:

- Mayor Eficiencia a Velocidades Altas: Los motores de corriente alterna, como los generadores síncronos de imanes permanentes, tienden a ser más eficientes a altas velocidades de viento. Esto puede resultar en una mayor producción de energía en áreas con vientos fuertes y constantes.
- Mayor Escalabilidad: Los sistemas de generación eólica a gran escala suelen utilizar motores de corriente alterna debido a su capacidad para escalarse fácilmente y generar grandes cantidades de electricidad.

- Requiere Inversores: Los motores de corriente alterna generan corriente alterna, por lo que se necesita un inversor para convertir la corriente en continua para su uso en la red eléctrica o en dispositivos de corriente continua. Esto puede agregar costos y complejidad al sistema.
- Menos Control de Velocidad: Los motores de corriente alterna pueden ser menos flexibles en términos de control de velocidad en comparación con los motores de corriente continua. Esto puede limitar la adaptabilidad del sistema a condiciones variables de viento.

### 6.3.3 Definición de redes eléctricas y mediciones del sistema

1. Identificación de Requisitos y Componentes
- Determina los Requisitos del Sistema: Se deben comprender las necesidades de alimentación de corriente continua para los equipos y las mediciones requeridas para los motores, incluyendo voltaje, corriente, tipo de sensores, entre otros.
- Selección de Componentes: Se deben comprender las necesidades de alimentación de corriente continua para los equipos y las mediciones requeridas para los motores, incluyendo voltaje, corriente, tipo de sensores, entre otros.
2. Diseño de Alimentación DC
- Fuente de Alimentación DC: Seleccionar la fuente de alimentación de corriente continua adecuada que cumpla con los requisitos de voltaje y corriente para los equipos, asegurándose de que pueda proporcionar la potencia necesaria.
- Distribución de Energía: Diseñar un sistema de distribución de energía que incluya reguladores de voltaje, interruptores y fusibles para garantizar un suministro de energía confiable y seguro a los equipos.
3. Cableado y Conexiones
- Selección de Cables: Seleccionarcables de corriente continua del calibre adecuado para minimizar las pérdidas de voltaje y garantizar conexiones seguras y confiables.
- Conexiones Correctas: Conectar los equipos a la fuente de alimentación de corriente continúa siguiendo las polaridades correctas y asegurándose de que todas las conexiones estén bien ajustadas.
4. Integración de Sistemas de Medición
- Sensores y Transductores: Conectar los equipos a la fuente de alimentación de corriente continua, siguiendo las polaridades correctas y asegurándose de que todas las conexiones estén bien ajustadas.
- Cableado de Sensores: Conectar los sensores a los controladores o instrumentos de medición utilizando cables adecuados y siguiendo las especificaciones del fabricante.

5. Configuración de Controladores e Instrumentación
- Programación de Controladores: Configurar y programar los controladores para adquirir y procesar datos de los sensores, así como para controlar el funcionamiento de los motores según sea necesario.
- Calibración: Realizar la calibración de los sistemas de medición para garantizar lecturas precisas y coherentes con las condiciones reales.
6. Pruebas y Validación
- Pruebas Iniciales: Realizar pruebas iniciales para asegurarse de que los equipos de corriente continua funcionen correctamente y de que los sistemas de medición proporcionen datos precisos.
- Ajustes y Optimización: Realizar ajustes en la configuración o en los controladores según sea necesario para optimizar el rendimiento del sistema.
7. Monitoreo y Mantenimiento
- Monitoreo Continuo: Implementar un sistema de monitoreo continuo para supervisar el funcionamiento de los equipos de corriente continua y los sistemas de medición.
- Mantenimiento | Regular: | Establecer | un | programa | de
mantenimiento preventivo para garantizar que todos | los
componentes estén en buen estado y reemplazar cualquier componente defectuoso.

### 7. ESPECIFICACIONES TÉCNICAS Y ESTÉTICAS

Mecanizado del proyecto

Base
Proceso para pintar la base con esmalte sintético proanox Materiales y herramientas necesarios:
- Acero ASTM A36 limpio y preparado.
- Esmalte sintético Proanox.
- Brochas, rodillos, o pistolas de pintura.
- Lijas de diferentes granos (80, 120, y 220).
- Papel de lija o lana de acero.
- Limpiador de superficies (puede ser agua y detergente suave).
- Trapos o paños limpios.
- Equipo de protección personal (gafas de seguridad, guantes, mascarilla).

Pasos para pintar sobre acero A36 con esmalte sintético Proanox:
Preparación de la superficie:

Comienza por asegurarte de que la superficie de acero A36 esté limpia, seca y libre de óxido, grasa, polvo o cualquier otro contaminante. Si la superficie tiene óxido, deberás eliminarlo con una lija o lana de acero y luego limpiarlo bien.

Lijado y preparación:

Lija la superficie con papel de lija de grano grueso (aproximadamente 80) para darle rugosidad y mejorar la adherencia de la pintura. Luego, lija nuevamente con papel de lija de grano más fino (120) para alisar la superficie. Finalmente, utiliza papel de lija de grano muy fino (220) para obtener una superficie suave.

Limpieza de la superficie:

Limpia la superficie lijada con un trapo o paño limpio y un limpiador de superficies adecuado o agua con detergente suave. Asegúrate de eliminar cualquier residuo de polvo o grasa.

Aplicación del esmalte:

Sigue las instrucciones específicas del fabricante del esmalte Proanox para su aplicación. Por lo general, se aplica con brocha, rodillo o pistola de pintura. Aplica una capa uniforme de esmalte sintético, siguiendo un patrón de pintura consistente. Puede ser necesario aplicar varias capas del esmalte, con tiempos de secado entre capas, según las recomendaciones del fabricante.

Secado:

Deja que el esmalte sintético seque completamente según las instrucciones del fabricante. El tiempo de secado puede variar según las condiciones ambientales y la marca del esmalte.

Inspección y retoque:

Después del secado, inspecciona la superficie en busca de áreas que puedan necesitar retoques o correcciones. Si es necesario, lija suavemente el área y aplica una capa adicional de esmalte.

Soldadura de orejas en la base
Para ensamblar todas las chapas y formar la base se colocarán orejas conectadas con puntos de soldadura para evitar los espacios que se generan al doblarlos, a su vez estas orejas tendrán un ancho de 20 mm y largo dependerá de la posición chapa es decir si es lateral, frontal, etc. El resultado se muestra en la siguiente figura:

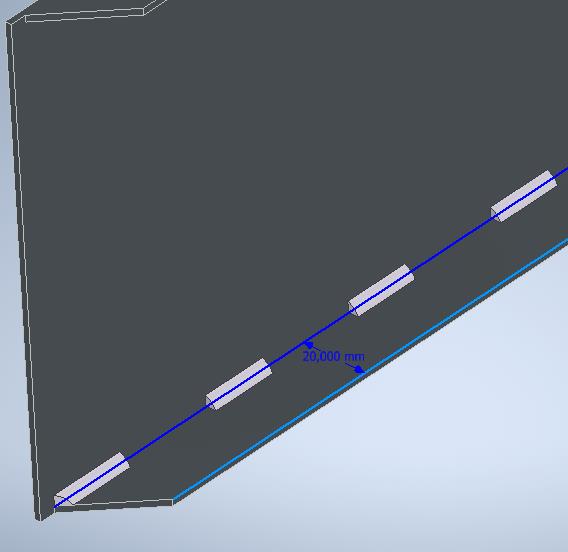
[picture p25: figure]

Figura 60: chapa con orejas soldadas

Uso de perfiles omegas
Para tener un refuerzo en la parte superior que es donde irán los prototipos se colocarán omegas soldadas de las partes laterales como se muestra en la figura 61, y en la figura 62 se muestra una vista explotada de todas las partes que conforman la base, para sujetar las chapas y formar la base se usarán pernos M5

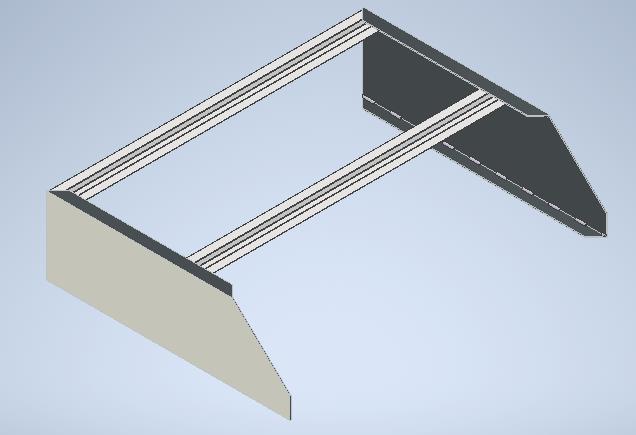
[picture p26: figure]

Figura 61: Omegas soldadas a las partes laterales

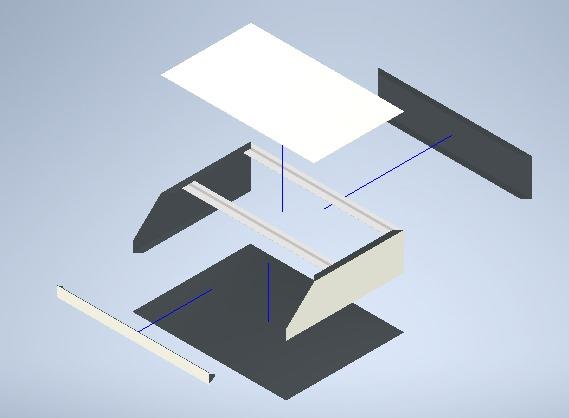
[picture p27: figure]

Figura 61: Vista explotada de chapas

Proceso de construcción
Corte de planchas
La plancha de acero de 1,1mm de espesor será cortada mediante laser, cada pieza requerida se especifica en la sección de planos. Considerar, que en las planchas metálicas también se deben realizar cortes de agujeros redondos para pernos, cuadrados para jaladeras, entre otros.

Soldadura de pestañas
Las piezas de plancha de las paredes laterales, superior, pared trasera y pared delantera necesitan ser fusionadas entre ellas, para ello se soldarán pestañas en las dimensiones que se aclaran en los planos, como se observa en la Figura 60, gracias a estas pestañas, después se podrá unir con pernos o tornillos las paredes.

Pintado de planchas con soldadura
Cuando cada plancha de pared se halla soldado con su correspondiente pestaña se procede a pintar todo el conjunto con pintura esmalte anticorrosivo como se detalla en la primera parte del documento.

Instalación de jaladeras
Con las paredes pintadas, se procede a instalar las jaladeras a presión, en los agujeros cortados en el primer paso.

Unión de paredes
Obtenidas las paredes con sus pestañas soldadas, se procede a unir las paredes usando pernos DIN 921 de 5 mm de diámetro por 8mm de largo; adjunto a tuercas BS 4183 y arandelas de 5 mm de diámetro.

Soldadura de perfil omega
Antes de colocar la tapa inferior, se debe soldar los perfiles omegas como se muestra en la figura 61, considerando que debe estar soldada tanto en las paredes laterales, como en la chapa metálica superior, puede ser soldad usando varios puntos de soldadura.

Instalación doble fondo
Con respecto al fondo de la estructura, primero se le debe instalar separadores y proceder con el doble fondo, donde se colocan los componentes electrónicos, finalmente la tapa se une con los pernos al resto de la estructura.

Instalación de placa frontal
Finalmente se debe instalar la placa frontal, donde se colocan los displays de datos, además de la configuración general del equipo, se deben usar los mismos pernos señalados con anterioridad.

Mecanizado del ventilador:
Materiales y herramientas necesarias:
- Motor eléctrico sin escobillas A2212/13T.
- Aspas del ventilador de 26 cm.
- Estructura de soporte.
- Cableado eléctrico.
- Tornillos y tuercas.
- Destornillador.
- Alicates.

Pieza de trabajo:
Se utilizarán dos piezas de acero HSS HRC63, las cuales tienen las siguientes medidas:

Pieza de acero HSS HRC63 de 350 mm x 100 mm x 40 mm

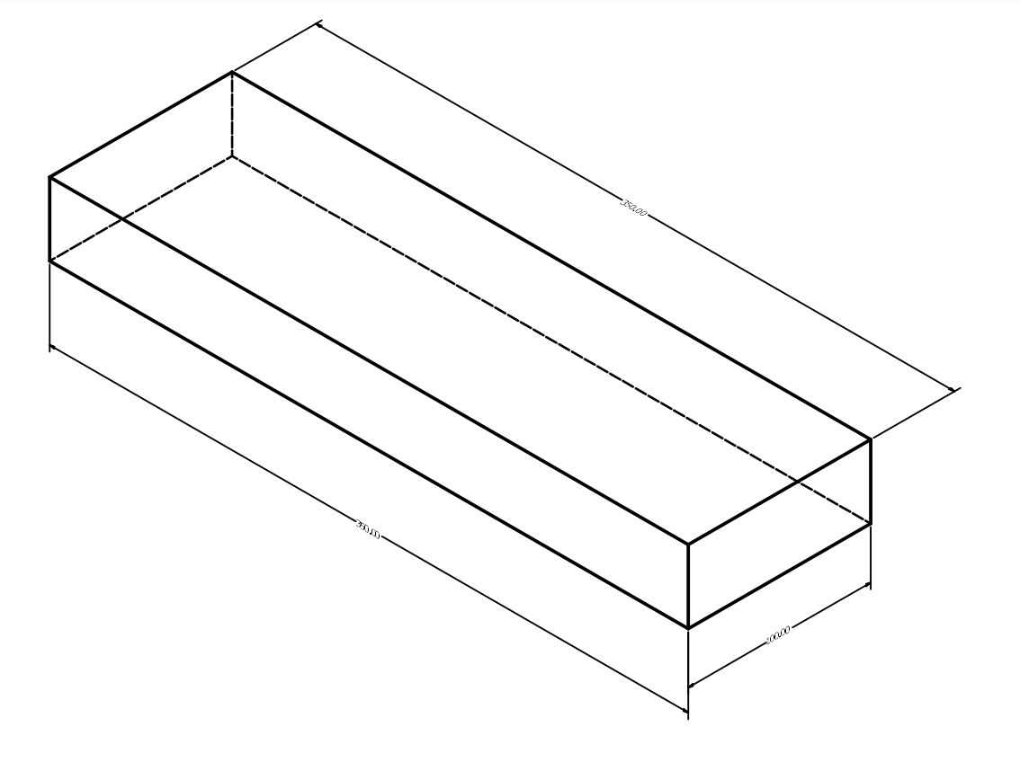
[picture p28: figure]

Pieza de acero HSS HRC63 de 350 mm x 300 mm x 50 mm

En base a un sistema de coordenadas de un bloque de 35cm x 12 cm x 310cm se realiza el maquinado.

Mecanizado de la base:
Antes de realizar el desbaste es necesario unir las dos placas de acero mediante soldadura MIG, generándose la siguiente estructura:

Eje X

Eje Y

Eje Z

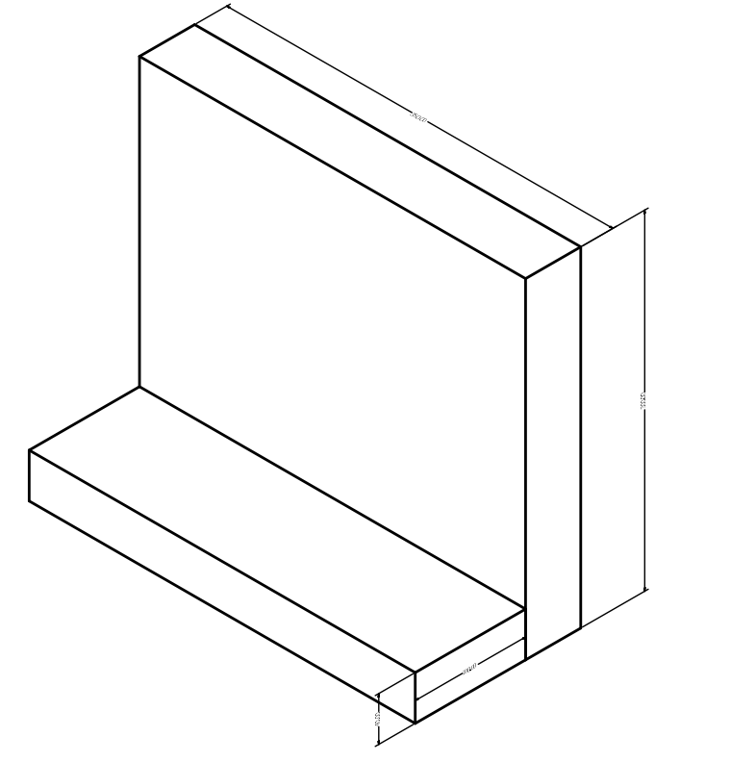
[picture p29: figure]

Para el desbaste de la pieza se utilizará una fresadora, el desbaste se dividirá en 3 procesos principales, los cuales son los siguientes:

1. Desbaste de 86 cm en el eje x, y de 311,36 cm en el eje y

2. Desbaste con interpolación lineal para que haya 2 cm de diferencia con la geometría esperada.
3. Desbaste en los bordes de 23 mm

Fina

Desbas

4. Fresado de 11 cm en el eje x, para la parte inferior

5. Interpolación circular de 148 cm de radio en el eje y, con una fresa plana de 40 mm de diámetro.

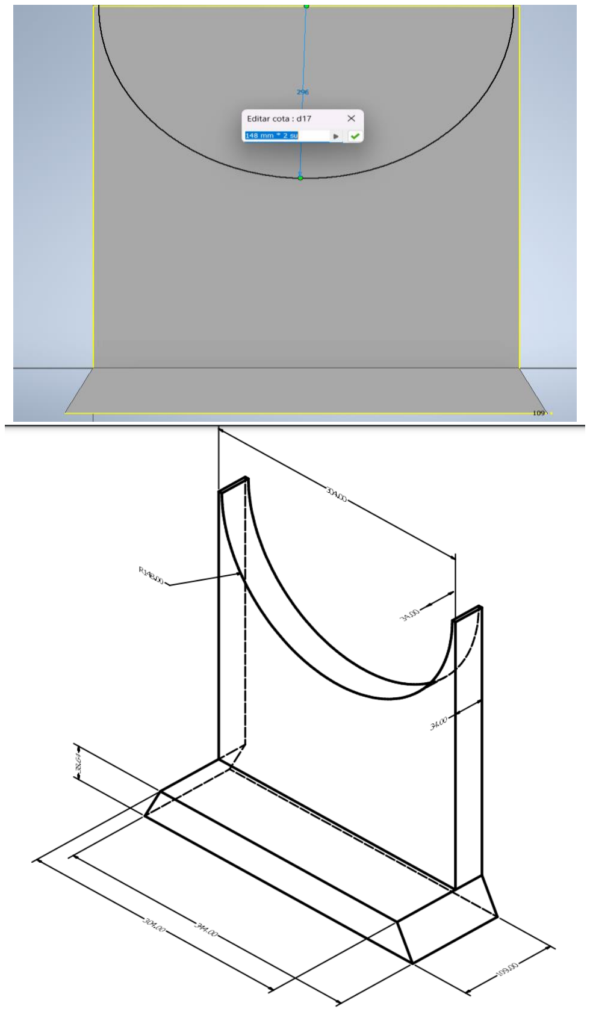
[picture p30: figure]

6. Acabado: La geometría obtenida tiene un espesor de 2cm respecto a la final, se requiere realizar un acabado con una profundidad de 2cm. Para la interpolación cuadrática aumentar el radio a 150 mm, y en toda la geometría quitar 2cm.

Orificios para Pernos de Conexión al Chasis:

Proceso: Se perforan orificios en la base de acero para la conexión con pernos al chasis del equipo.

1. Taladrado de 4.5 mm de diámetro para el agujero pasante
2. Taladrado de 5 mm de diámetro obteniendo un espesor de 2 mm para conexión con el chasis.

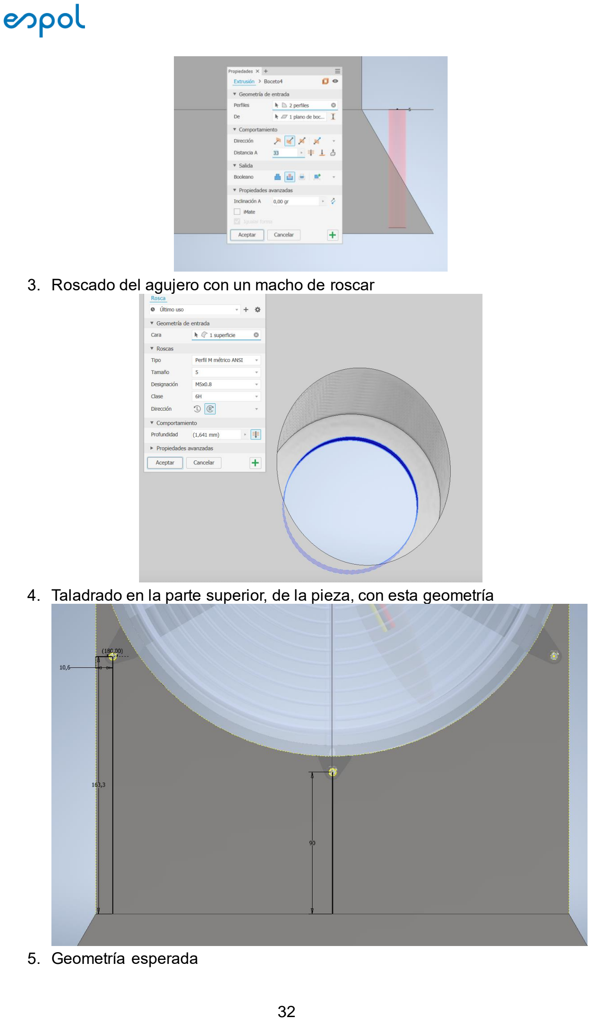
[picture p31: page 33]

3. Roscado del agujero con un macho de roscar
4. Taladrado en la parte superior, de la pieza, con esta geometría
5. Geometría esperada

Proceso de Mecanizado de la Rendija de Protección:
Proceso: Se utilizará el moldeado como proceso de mecanizado, además de utilizar adhesivo epoxi para unir la vara de acero con la rendija de plástico.

Justificación: La rendija de protección garantiza la seguridad al evitar el acceso a las aspas en movimiento y, al mismo tiempo, no interfiere significativamente con el flujo de aire generado por el ventilador. Además, el adhesivo epoxi es fuerte y versátil, adecuado para unir metales y plásticos, ofreciendo una unión duradera y resistente.

Moldeado de la parte frontal de la rendija:
- La parte frontal se divide en dos piezas, la pieza con la cual se va a empernar a la base, y la pieza que une las varas metálicas.

Unió

Pieza a
empern

- Para la pieza de unión, es suficiente con tener un cilindro de plástico de 80 mm de diámetro y 10 mm de alto.
- La pieza para empernar se genera mediante un molde con las siguientes dimensiones. Teniendo un espesor de 3mm.

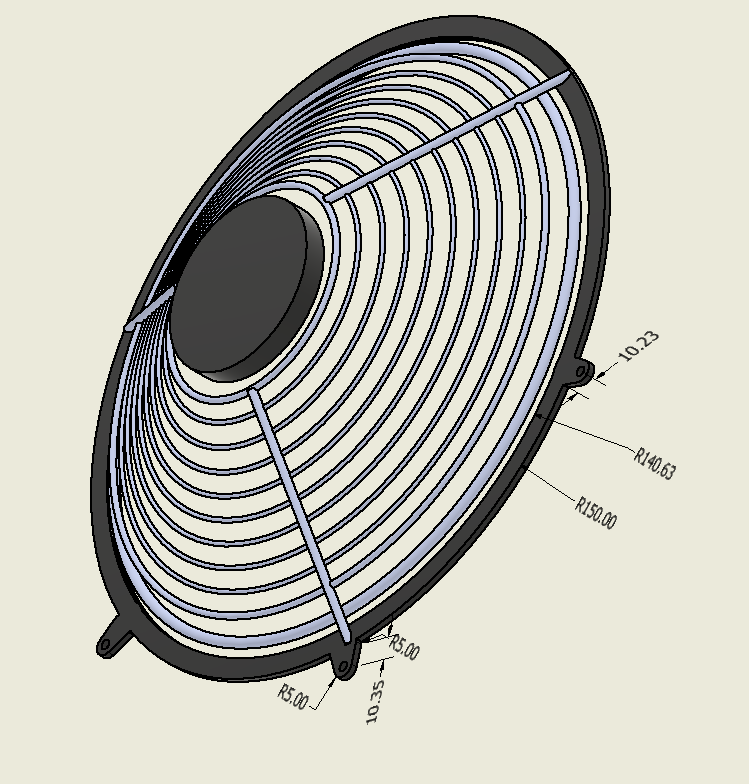
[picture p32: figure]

- Las varillas se dividen en 2 tipos, varillas circulares, y lineales.

- Las varillas lineales ni circulares no necesitan mecanizado. las varillas lineales son cilindros de acero de 4 mm de radio, y 115 de alto. Mientras que las varillas circulares son cilindros que descienden su diámetro desde 274 mm a 95 mm, disminuyendo 15 mm de diámetro por cada varilla acoplada. El acople se realiza teniendo un angulo de 35 º, de tal forma que quede así.

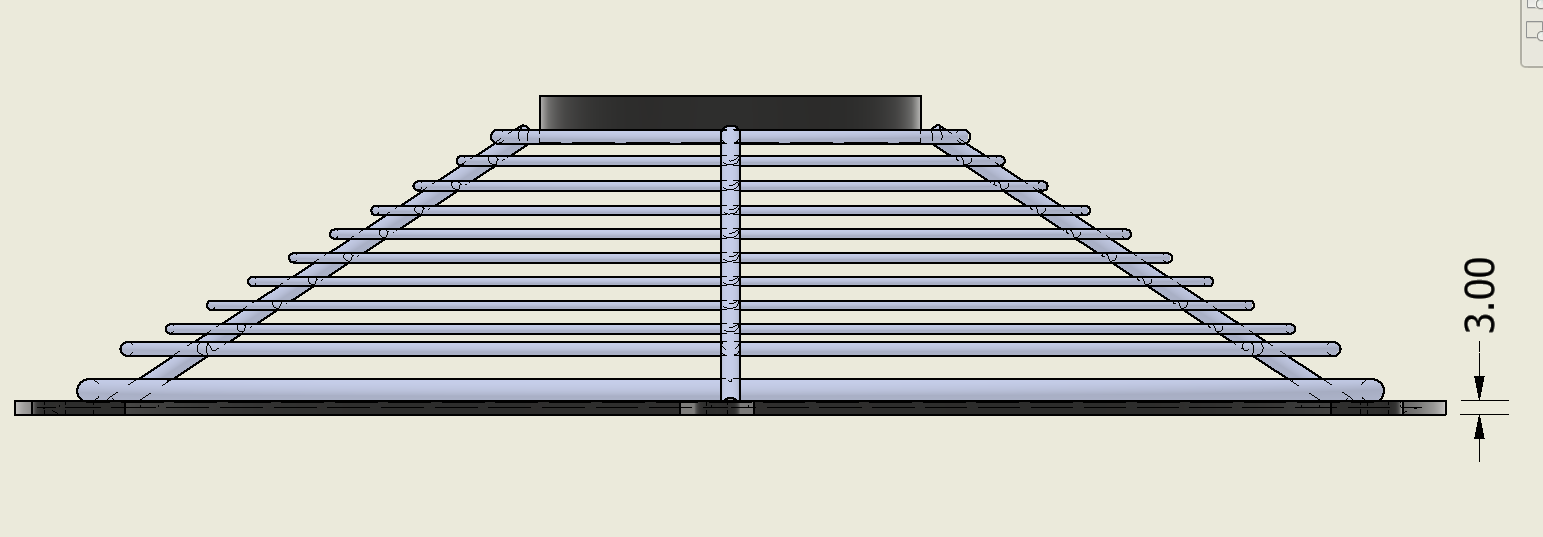
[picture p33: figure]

Moldeado de la parte posterior de la rendija:

- La parte posterior de la rendija también es por moldeado, se utilizan las mismas medidas que para la parte frontal, sin embargo, se agrega una sección para poder colocar el motor sin escobillas, y una perforación para poder ubicar el eje de este.

Material para las Aspas y la Base:
Material: Acero al carbono para las aspas y la base.

Justificación: El acero al carbono es resistente y duradero, adecuado para soportar las fuerzas y condiciones de funcionamiento de un ventilador. Además, es un material ampliamente disponible en el mercado ecuatoriano.

Anemómetro
Consideraciones generales:
Tipo de Plaquita para Torno:

Se utilizan plaquitas de metal duro tipo WNMG (ISO designación WNMG080408) para los procesos de torneado.

Justificación: Las plaquitas de metal duro garantizan un mecanizado preciso y duradero en los materiales utilizados, optimizando la eficiencia de las operaciones de torneado.

Materiales y herramientas necesarias:
- Eje de acero de 6 mm de diámetro.
- Barra de nylon, cilindro macizo, PA6, buje de anillo de nylon, 50 mm x 40 cm
- reducción – Ampliación de PVC Cónica Concéntrica de 60 mm a 30 mm de diámetro exterior

- Rodamientos radial y axial.
- Perno de acero para la conexión entre el eje y la manzana.
- Brida de acero para fijación en la base.
- Tipo de perno: Perno Allen de acero.
- Herramientas de mecanizado: Torno, fresadora, taladro.

Mecanizado del anemómetro
El anemómetro se divide en 5 partes, y son las siguientes:
1. Hélice


2. Conexión entre el eje y la hélice.
3. Tapa superior
4. Cuerpo central
5. Brida personalizada

Proceso de Mecanizado del Eje: Refrentado del Extremo:

Proceso: Se refrenta el extremo del eje de acero de 6 mm de diámetro en un torno hasta alcanzar 5 mm de diámetro en un largo de 1.5 mm. Se utiliza una plaquita de corte de metal duro para garantizar una superficie precisa y lisa.

Justificación: El refrentado asegura un ajuste preciso del eje en el rodamiento axial, permitiendo un movimiento suave y eficiente.

Cuerpo del Anemómetro:
Tapa superior: Se inserta una reducción – Ampliación de PVC Cónica Concéntrica de 60 mm a 30 mm de diámetro exterior.


Maquinado de la base:
Proceso: Se mecaniza la barra de nylon de 50 mm para realizar la base del anemómetro.

Justificación: La ranura proporciona el alojamiento adecuado para el rodamiento axial, garantizando su alineación y funcionalidad.

Resultado final esperado:


Fresado: La brida presente en la base del tubo se la realizará mediante un fresado de una pieza de 10 x 100 x 50 mm, con interpolación cuadrática de 25 mm de radio. De tal manera que la pieza de trabajo sea esta:

Mediante un desbaste de la superficie superior de 3 mm y un acabado en la superficie inferior y superior de 1 mm cada uno, se rebaja el espesor a 5 mm, además, mediante una interpolación cuadrática de 25 mm de radio se genera la brida esperada.


Con el mismo adhesivo epoxi se une la brida a la base de la barra de nylon de 50 mm.

Mecanizado de la barra de nylon
Perforados: Para el mecanizado de la barra de nylon, solo se requieren de perforaciones en los puntos que se muestran a continuación. Se utilizan brocas de 3.4, 4.5, 7, 12 y 45 mm para los orificios presentes en la pieza.

El perforado de 12 mm es escencial, pues ahí se ubicara el rodamiento axial del anemómetro.

Para el perforado lateral de 10 mm, se requiere de un movimiento helicoidal de una fresa de 8 mm, o en su defecto, utilizar una broca de 10 mm.


Proceso de Mecanizado para la Conexión de Aspas con el Eje:
Perforación para Perno:

Proceso: Se perfora una apertura en la manzana que conecta las aspas con el eje utilizando un taladro de 2 mm de diámetro.

Justificación: La perforación permite la conexión segura entre el eje y la manzana, manteniendo estable la unión con las aspas.

Diseño eléctrico:

Se está diseñando una configuración para alimentar un sistema en el cual uno de los dispositivos demanda de 12 voltios medinate una fuente de corriente Alterna tipica de 120V 50Hz , para ello por motivos ténicos se utiliza una fuente de alimentación conmutada. Esta fuente de alimentación se encargará de realizar la conversión y regulación del voltaje. A continuación, se describen los componentes y justificaciones

### 1. Conexiones eléctricas: dado a consideración conceptual del sistema el

tipo de cable cobre a considerar es de 18AWG y 22AWG. El primero menicionado tiene la finalidad de tolerar mayor amperaje dentro un cirquito electrico clave para las condiciones de operación del motor 555DC, usualmente es de 7 a 8 amperios.Y el último mencionado es común dentro de las conexiones que operen menor a 6 amperior lo cual lo hae ideal para cirquitos de controladores.

Ilustración 19 Calibre de tipos de cable

### 2. Fuente de Alimentación de 12 Voltios: Se empleará una fuente de

alimentación que ofrezca una tensión nominal de 12 voltios cons dos salidas. Esta fuente de energía proporcionará la tensión requerida para el funcionamiento del dispositivo final.La potencia de la fuente queda en función del consumo de los dispositivos dentro del sistema. En este caso se considera emplear una fuente.

En este caso considerando que el cirquito de potencia, generador de flujo de volumetrico, posee una tension de 12V y un corriente de 6A. El consumo del dominante es de 72 Vatios considerando un consumo bajo para el resto de compontes.


Ilustración 20 Fuente conmutada de 12V

Se sobre dimensiona la fuente comutada de 12V amperaje de 10 A y una potencia de 120 Vatios

### 3. Fuentes de reductoras de voltaje y sensores: Se emplea una reducción

de 5v debido a que las pantallas de 7 segmentosn y otros dispositivos de control estan diseñadas para un voltaje nominal antes nombrado por ello es crucial reducirlo.

La fuente a emplear es un reductor de voltaje StepDown, este posee unos diferentes rangos de operación generalmente va de los de 33.v a los 15V, por medio de un trimer se realiza el respectivo ajuste a 5V aproximandamente.


Ilustración 21 Reductor de voltaje StepSDown 5v

### 4. Arduino con shield: Se utilizará un Arduino Uno como controlador

principal del sistema. Este microcontrolador es versátil y ampliamente compatible con una variedad de módulos y sensores. Para facilitar las conexiones, se empleará el shield Screw Shield, que permite una conexión rápida y segura de los componentes a través de terminales de tornillo.

- Arduino Uno: El Arduino Uno se encargará de coordinar todas las operaciones del sistema, incluida la lectura de sensores, el control del motor BLDC a través del ESC y la visualización de datos en la pantalla de 7 segmentos. Se debe programar con un código adecuado para las funciones requeridas.

Ilustración 22 Arduino UNO

- Screw Shield: El shield Screw Shield se conecta directamente a la placa Arduino Uno y facilita la conexión de cables y componentes mediante terminales de tornillo. Esto mejora la fiabilidad de las conexiones y simplifica la instalación de componentes adicionales.


Ilustración 23 Screw Shield Arduino UNO

### 5. Sensor de voltaje y corriente: Para monitorear el consumo de corriente

y la tensión del sistema, se utilizará el módulo INA219. Este dispositivo permite medir la corriente en el circuito y proporciona una lectura precisa de la tensión.

- INA219: El módulo INA219 se conectará al Arduino a través de pines adecuados y se configurará para medir la corriente y la tensión en el sistema. Los datos recopilados por el INA219 son útiles para el monitoreo y el control del sistema.

Ilustración 24 INA 219

### 6. Motor BLDC con ESC: Se empleará un motor Brushless DC (BLDC) para

el ventilador del sistema. Este tipo de motor es eficiente y proporciona un control preciso de la velocidad. Para controlar el motor, se utilizará un ESC (Electronic Speed Controller) o controlador electrónico de velocidad.

- Motor BLDC: El motor BLDC debe tener una clasificación de corriente de al menos 9 amperios para funcionar a su máxima capacidad. Se conectará al ESC para permitir el control de la velocidad y la dirección del giro.


Ilustración 25 Motor sin escobillas

- ESC BLDC: El controlador electrónico de velocidad se encargará de recibir las señales de control del Arduino y ajustar la velocidad del motor BLDC en consecuencia. Se debe configurar y calibrar adecuadamente para garantizar un funcionamiento óptimo del motor.

Ilustración 26 ESC BLDC

### 7. Funcionamiento del anemómetro: El anemómetro se utilizará para

medir la velocidad del viento en rpm (revoluciones por minuto). Está equipado con un encoder y un disco de encoder que se conectan directamente al Arduino para registrar y mostrar la velocidad del viento.


Ilustración 27 Encoder

- Conexión al Arduino: Los cables del encoder se conectarán a los pines digitales del Arduino para contar los pulsos y calcular la velocidad del viento en rpm. El código en el Arduino procesará estos datos y los mostrará en la pantalla de 7 segmentos o realizará otras acciones según sea necesario.

### 8. PCBS : Dadas las condiciones previamente mencionadas para alimentar

un dispositivo con 12 voltios utilizando una fuente conmutada, se puede realizar una placa de circuito impreso (PCB) para integrar los componentes de manera eficiente. En la PCB, se diseñarán las rutas de conexión, los pads y las pistas necesarias para que los componentes funcionen correctamente y se comuniquen entre sí. Esto optimizará el espacio y la eficiencia, asegurando un suministro de 12 voltios estable y eficiente para el dispositivo.

Especificamente se deben realizar la integracion de dipositivos luminicos de 7 segmentos , un integrado 74HC595 y pines para sistematizar las conexiones.

Ilustración 28 Pcb Renderizada en 3D

Ilustración 29 Diseño electrónico de pcb en Proteus

Adicionalmente se requiere una pcb para fijar las cargas lumínicas del generador eléctrico.

Ilustración 30 Pcb Renderizado en 3D

Ilustración 31 Diseño de PCB en Proteus

### 9. Conexiones con el controlador:

El diagrama esquemático respectivo va asociado con la funcionalidad que tiene nuestro dispositivo. En este caso debe ser capaz de obtener medir la energía eléctrica producida por el generador y transformar los datos en los valores representativos de un generador como voltaje, amperaje, potencia y velocidad.


Ilustración 32 Diagrama Esquemático elétrico del generador eolico

Por medio de diagrama anterior es posible evidenciar de manera sencilla las conexiones de alimentación, entradas análogas como sensor de amperaje y voltaje, cirquito de potencia del generador de aire con el controlador por medio de un potenciómetro y cirquito de señalización de valores por medio de las pantallas de 7 segmentos y su respectivo integrado.

Para una representación mejor se muestra cableado por medio de la herramienta de inventor para una mayor compresión de este.

Ilustración 33“Presentación General del diseño”- Inventor 2024

Ilustración 34“Cirquito eléctrico principal del fondo eléctrico” - Inventor 2024

Ilustración 35“Cirquito de secundario, representación numérica y cargas eléctricas” – Inventor 2024

Representación
- En la parte izquierda se encuentran las respectivas conexiones de potencia, el controlador BLCD y las conexiones respectivas para el control del motor.

- En la parte de en medio se encuentra el Arduino y las Pcbs respectivas para generar los valores lumínicos de medición del sistema
- En la parte derecha la fuente de alimentación de 12V DC, StepDown DE 5V y borneras en serie para alimentar las placas PCB – sensor de voltajecorriente

Materiales:
- 3 borneras en serie
- 1 controlador BLC
- 4 pantallas de 7 segmentos
- 4 integrados hcf4017
- Placas PCB
- Fuente conmutada de 12V
- Sensor de voltaje y corriente INA129
- Reductor de voltaje StepDown 4.3v a 15 V

10.Código

1. #include "LedControl.h" // Library used for communcation with 7 segment
2. #include <Wire.h>
3. #include <Adafruit_INA219.h>
4.
5. Servo ESC; // create servo object to control the ESC 6.
7. int potValue; // value from the analog pin
8.
9. LedControl lc = LedControl(4,2,3,1); // (DIN, CLK, LOAD, number of Max7219 chips)
10. LedControl lc2= LedControl(12,10,11,1);
11.
12. float shuntvoltage = 0;
13. float busvoltage = 0;
14. float current_mA = 0;
15. float loadvoltage = 0;
16. float power_mW = 0;
17.
18. Adafruit_INA219 ina219; 19.
20. void setup() {
21. uint32_t currentFrequency; 22.
23. Serial.begin(9600);
24. while (!Serial) {
25. // will pause Zero, Leonardo, etc until serial console opens
26. delay(1);
27.
28. // Attach the ESC on pin 9
29. ESC.attach(9,1000,2000); // (pin, min pulse width, max pulse width in microseconds)
30. }
31.
32. // Initialize the INA219.
33. // By default the initialization will use the largest range (32V, 2A). However
34. // you can call a setCalibration function to change this range (see comments).

35. if (! ina219.begin()) {
36. Serial.println("Failed to find INA219 chip");
37. while (1) { delay(10); }
38. }
39.
40. ina219.setCalibration_32V_2A();
41.
42. lc.shutdown(0,false); // Wake up MAX7219
43.
44. lc.setIntensity(0,7); // Set brightness to medium
45.
46. lc.clearDisplay(0); // Clear all displays connected to MAX7219 chip # 47.
48. lc2.shutdown(0,false); // Wake up MAX7219
49.
50. lc2.setIntensity(0,7); // Set brightness to medium
51.
52. lc2.clearDisplay(0); // Clear all displays connected to MAX7219 chip # 53.
54. // Put zeros on both displays at startup
55. lc.setDigit(0,0,0,false); // (Max7219 chip #, Digit, value, DP on or off)
56. lc.setDigit(0,1,0,false);
57. lc.setDigit(0,2,0,false);
58. lc.setDigit(0,3,0,false);
59. lc.setDigit(0,4,0,false); // (Max7219 chip #, Digit, value, DP on or off)
60. lc.setDigit(0,5,0,false);
61. lc.setDigit(0,6,0,false);
62. lc.setDigit(0,7,0,false);
63.
64. lc2.setDigit(0,0,0,false); // (Max7219 chip #, Digit, value, DP on or off)
65. lc2.setDigit(0,1,0,false);
66. lc2.setDigit(0,2,0,false);
67. lc2.setDigit(0,3,0,false);
68. }
69.
70.
71. void loop() {
72. shuntvoltage = ina219.getShuntVoltage_mV();
73. busvoltage = ina219.getBusVoltage_V();
74. current_mA = ina219.getCurrent_mA();
75. power_mW = ina219.getPower_mW();
76. loadvoltage = busvoltage + (shuntvoltage / 1000);
77.
78. Serial.print("Current: "); Serial.print(current_mA); Serial.println(" mA");
79. Serial.print("Load Voltage: "); Serial.print(loadvoltage); Serial.println(" V");
80. | Serial.print("Power: | "); Serial.print(power_mW); Serial.println(" mW");
81.
82. int current_mA2 = current_mA;
83. int Amilesima= (current_mA2/1000) % 10;
84. int Acentena= (current_mA2/100) % 10;
85. int Adecena= (current_mA2/10) % 10;
86. int Aunidad= current_mA2 % 10;
87.
88. lc.setDigit(0,0,Amilesima,false); // (Max7219 chip #, Digit, value, DP on or off)
89. lc.setDigit(0,1,Acentena,false);
90. lc.setDigit(0,2,Adecena,false);
91. lc.setDigit(0,3,Aunidad,false);
92.
93. int loadvoltage2= loadvoltage*100;
94. int Vdecena= (loadvoltage2/1000) % 10;
95. int Vunidad= (loadvoltage2/100) % 10;
96. int Vdecimal1= (loadvoltage2/10) % 10;
97. int Vdecimal2= loadvoltage2 % 10;
98.
99. lc.setDigit(0,4,Vdecena,false); // (Max7219 chip #, Digit, value, DP on or off)

100. lc.setDigit(0,5,Vunidad,true);
101. lc.setDigit(0,6,Vdecimal1,false);
102. lc.setDigit(0,7,Vdecimal2,false); 103.
104. int power_mW2= power_mW;
105. int Wmilesima= (power_mW2/1000) % 10;
106. int Wcentena= (power_mW2/100) % 10;
107. int Wdecena= (power_mW2/10) % 10;
108. int Wunidad= power_mW2 % 10;
109.
110. lc2.setDigit(0,0,Wmilesima,false); // (Max7219 chip #, Digit, value, DP on or off)
111. lc2.setDigit(0,1,Wcentena,false);
112. lc2.setDigit(0,2,Wdecena,false);
113. lc2.setDigit(0,3,Wunidad,false);
114. delay(500);
115.
116. | potValue = analogRead(A0); | // reads the value of the potentiometer (value between
0 and 1023)
117. | potValue = map(potValue, 0, 1023, 0, 180); | // scale it to use it with the servo
library (value between 0 and 180)
118. | ESC.write(potValue); | // Send the signal to the ESC
119. }
120.

Análisis de código:

Este es un fragmento de código de Arduino que sirve para controlar un motor eléctrico (ESC) y visualizar datos de un sensor de corriente eléctrica en una pantalla LED de 7 segmentos. A continuación, se detalla su funcionalidad:

### 1. Inclusión de Bibliotecas:

- Se incluyen las bibliotecas necesarias para la comunicación con un controlador de pantalla LED de 7 segmentos (LedControl), para la comunicación I2C (Wire) y para la lectura de datos de un sensor de corriente eléctrica (Adafruit_INA219).

### 2. Declaración de Variables y Objetos:

- Se declaran variables y objetos necesarios, como "potValue" para almacenar el valor del potenciómetro, objetos "lc" y "lc2" para el control de las pantallas LED de 7 segmentos, y objetos para medir datos del sensor de corriente (shuntvoltage, busvoltage, current_mA, loadvoltage, power_mW).

### 3. Configuración Inicial (setup):

- En esta sección, se configuran los parámetros iniciales del programa.
- Se inicializa la comunicación serie (Serial).

- Se configura el servo motor (ESC) en el pin 9 con sus valores de pulso mínimo y máximo.
- Se inicializa el sensor de corriente (INA219) y se establece su calibración para medir en el rango deseado.

### 4. Configuración de Pantallas LED:

- Se configuran las pantallas LED de 7 segmentos para su funcionamiento, estableciendo el brillo y limpiando las pantallas.

### 5. Bucle Principal (loop):

- En el bucle principal, se realizan las siguientes tareas:
- Se leen datos del sensor de corriente (shuntvoltage, busvoltage, current_mA, power_mW, loadvoltage) y se imprimen en el monitor serie.
- Se procesan y muestran en las pantallas LED de 7 segmentos los valores de corriente, voltaje y potencia.
- Se lee el valor del potenciómetro conectado al pin A0 y se ajusta el ángulo del servo motor (ESC) según ese valor, lo que controla la velocidad o posición del motor.

### 8. FUNCIONALIDAD Y USABILIDAD:

Dentro del diseño del generador eólico a escala, se encuentra una forma de obtener energía renovable y limpia mediante la fuerza del viento para alimentar diferentes dispositivos electrónicos y proporcionar iluminación en viviendas. La energía cinética generada por las corrientes de aire impulsa las palas del generador eólico, lo que inicia su movimiento. A través de un sistema interno de engranajes, esta energía cinética se transmite al motor. Un transformador eleva la tensión, generando así la energía necesaria para su utilización.

Este generador eólico no solo produce energía de manera eficiente, sino que también contribuye significativamente a la reducción del consumo de combustibles fósiles, la contaminación del aire y el agua, la descentralización de la energía eléctrica y fomenta el desarrollo sostenible en la comunidad.

El proyecto tiene como objetivo educar sobre los conceptos de las energías renovables. Históricamente, el viento ha sido aprovechado por la humanidad en diversas aplicaciones, desde la navegación hasta la molienda de granos y la extracción de agua. En el siglo XX, se comenzó a utilizar para la generación de energía eléctrica. Hoy en día, dado el alto consumo de energía eléctrica a nivel global, es fundamental buscar alternativas que no dañen el medio ambiente. En este contexto, se opta por la energía eólica, aprovechando la energía cinética de las corrientes de aire.

Este proyecto destaca la transformación de la energía, desde la energía cinética del viento hasta la energía mecánica en el mecanismo interno y, finalmente, en forma de energía eléctrica para el consumo humano. También enfatiza la conciencia ambiental, la educación en este campo, la aplicación de conceptos de física en la práctica, la discusión de aspectos técnicos y los costos de producción. Además, busca fomentar la creación de experimentos prácticos y sencillos para mejorar la comprensión de estos conceptos entre los estudiantes.

### 9. COSTOS

Para la simulación CAD fue necesario primero definir algunos aspectos de la estructura, en este caso las piezas fueron

Item | Componentes | Descripción | Cantidad | Precio ($) | Precio Total
Referencia
1 Eje de acero de | 6 mm | Ejes AISI 304 (Inoxidable) | 2 | $5.00 | $10.00 | https://dipacmanta.com/producto/ejes/aisi-304-inoxidable/ejes-aisi-304-inoxidable/
2 | Acople flexible | ACOPLE ACOPLAMIE NTO FLEXIBLE DE ALUMINIO PARA MOTORES | 1 | $2.76 | $2.76 | https://tecmikro.com/componentes-electromecanicos/518 -acople-acoplamiento-flexible.html
3 | Abrazadera | Abrazadera Industrial Acero Inoxidable | 4 | $0.45 | $1.80 | https://bpecuador.com/producto/abrazadera-industrial-acero-inoxidable/
4 | Arandelas de prueba redonda (métrico) (IFI) | Arandela plana galvanizada, funda de 12u, seleccione el diámetro. | 3 | $0.39 | $1.17 | https://www.lacasadelcarpintero.com.ec/arandela-plana/
5 | Pie de amigo | PIE DE AMIGO (DOCENA) EV | 4 | $0.37 | $1.48 | https://www.elferretero.com.ec/products/32 0
6 | Potenciometro | POTENCIOM ETROS DE PERILLA | 1 | $0.35 | $0.35 | https://roboticsec.com/producto/potenciometros-de-perilla/
7 | Switch | SWITCH INTERRUPT OR 2 PINES | 5 | $1.34 | $6.70 | https://roboticsec.com/producto/switch-interruptor-2-pines/
8 | Helice | Por impresión 3D | 3 | $1.00 | $3.00
9 | Motor dc 555 | Funciona con 12 voltios, permite el control de un motor CC con el temporizador 555. | 1 | $14.90 | $14.90 | https://www.vilconsa.com/viewdetalle.php?id_articulo=1592

10 | Encoder | ENCODER ROTATORIO | 1 | $3.00 | $3.00 | https://roboticsec.com/producto/encoder-rotatorio/
11 | Prensaestopas | PRENSA ESTOPA 5/16 | 6 | $1.00 | $6.00 | https://inselec.com.ec/store/inicio/2565-prensa-estopa-5-16-ref-p-1320-.html
12 | Motor BLDC | 24v 26w 4000rpm Nema 17 Brushless DC Motor BLDC Motor | 1 | $12.97 | $12.97 | https://www.alibaba.com/product-detail/24v-26w-4000rpm-Nema-17-Brushless_1600323263757.html?spm=a270 0.7735675.0.0.5e9dvP s2vPs2Tk&s=p
13 | Controlador BLDC | XY-BLDC DC 12~30V 200W 3 Phase DC Brushless Hall Motor Speed Controller Module Motor Drive Module | 1 | $6.00 | $6.00 | https://www.alibaba.com/product-detail/XY-BLDC-DC-12-30V-200W_1600899833737.html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
14 | Barra de nylon 12 mm x 400 mm | Nylon En Barra De 12mm De Diámetro X 1000mm De Largo | 1 | $2.50 | $2.50 | https://bohman.com.ec/shop/product/nylon-6a-barra-blanco-1-m-12136#attr=7068,708 0
15 | Reducción – Ampliación de PVC Cónica Concéntrica de 60 mm a 30 mm de diámetro exterior | Reduccion conica PVC encolar D-63/50/40 mm. PN-16 | 1 | $2.50 | $2.50 | https://www.corefluid.es/product/reduccion-conica-pvc-encolar-d-63-50-40-mm-pn-16/
16 | Rodamientos radial | RODAMIENT O RADIAL 6 mm | 1 | $3.00 | $3.00 | https://bohman.com.ec/shop?search=RODA MIENTO+DE+BOL AS&order=

16 | Rodamientos radial | RODAMIENT O RADIAL 8 mm | 1 | $3.00 | $3.00 | https://bohman.com.ec/shop?search=RODA MIENTO+DE+BOL AS&order=
17 | Rodamientos axial | RODAMIENT O AXIAL DE BOLAS -51213 5 mm | 1 | $3.00 | $3.00 | https://bohman.com.ec/shop/product/20-isb-51213-rodamiento-axial-de-bolas-51213-14400#attr=17212,17 213,17214,17215
17 | Rodamientos axial | RODAMIENT O AXIAL DE BOLAS -51213 8 mm | 1 | $3.00 | $3.00 | https://bohman.com.ec/shop/product/20-isb-51213-rodamiento-axial-de-bolas-51213-14400#attr=17212,17 213,17214,17215
18 | Chumaceras | KFL08 DIAMETRO 8mm | 1 | $3.00 | $3.00 | https://roboticsec.com/producto/kfl08-diametro-8mm/
19 | Polea | POLEA GT2 16 DIENTES DIAMETRO 5mm | 1 | $3.50 | $3.50 | https://roboticsec.com/producto/polea-gt2-16-dientes-diametro-5mm/
20 | Polea | POLEA GT2 60 DIENTES DIAMETRO 8mm | 1 | $10.00 | $10.00 | https://roboticsec.com/producto/polea-gt2-60-dientes-diametro-8mm/
21 | Polea | POLEA SIN DIENTES DIAMETRO 5mm | 1 | $5.00 | $5.00 | https://roboticsec.com/producto/polea-sin-dientes-diametro-5mm/
22 | Correa | CORREA DENTADA GT2 CERRADA 200mm | 1 | $2.75 | $2.75 | https://roboticsec.com/producto/correa-dentada-gt2-cerrada-200mm/

23 | Adhesivo epóxico transparente, pega cerámica, Fusión Epoxy, 30 g | Proporciona una adherencia fuerte y permanente incluso bajo vibración e impacto | 1 | $30.00 | $30.00 | https://www.3m.com.ec/3M/es_EC/p/d/v000242353/
24 | Espadín macho 90° simple (40 pines) | Espadín header macho a 90° simple, separación de 2,54 mm (40 pines por unidad). | 1 | $0.75 | $0.75 | https://roboticsec.com/producto/1x40-header-macho- en-l-90-grados/
25 Espadín macho | simple (40 pines) | Espadín header macho, separación de 2,54 mm (40 pines por unidad). | 1 | $0.50 | $0.50 | https://roboticsec.com/producto/1x40-header-macho- negro/
26 Terminal tipo | puntera (18-22AWG) | Terminal tipo puntera, cubierta de PVC (100 terminales por unidad). | 2 | $1.57 | $3.14 | https://www.ingelcom.com.ec/shop/terminal -aislado- puntera-18-22-awg-amarillo-ingelcom-14434#attr=
27 Terminal tipo | horquilla (22-16 AWG) | Calibre mm2: 0.5-1; Perno: #10 (3/16´´); Calibre AWG: 22-16; Color: Rojo; Apertura de la U: 5.3mm (100 por unidad). | 1 | $5.17 | $5.17 | https://electricoindustrial.com.ec/producto/te rminales- aislados-tipo-horquilla-camsco/
28 Terminal tipo | ojo o anillo 1,25-5 | Mini terminal de ojo rojo con protector. Para conexión a tierra (1 por unidad). | 6 | $0.10 | $0.60 | https://www.vilconsa.com/viewdetalle.php?id_articulo 15356
29 | Cable AWG 22 múltiples colores | Se comprará 7 colores disponibles (no hay disponibles negro y rojo) (precio por metro). (2 por cada color) | 14 | $0.15 | $2.10 | Otech Electronics

30 Cable estañado | para conexiones , 22 AWG, color negro (metro) | Cable estañado para conexiones, color negro, calibre 22 AWG, útil para conexión de circuitos eléctricos y electrónicos. Se vende por metro. | 2 | $0.25 | $0.50 | https://www.steren.com.ec/cable-esta-ado-para- conexiones-22-awg-color-negro.html
31 Cable estañado | para conexiones , 22 AWG, color rojo (metro) | Cable estañado para conexiones, color rojo, calibre 22 AWG, útil para conexión de circuitos eléctricos y electrónicos. Se vende por metro. | 2 | $0.25 | $0.50 | https://www.steren.com.ec/cable-estanado-para- conexiones-color-rojo-calibre-22-awg.html
32 Cable Flexible | #18 AWG Rojo por Metro | Para la corriente AC. | 2 | $0.45 | $0.90 | https://megatronica.cc/producto/cable-flexible-18-awg- rojo-por-metros/
33 Cable Flexible | #18 AWG Negro por Metros | Para la corriente AC. | 2 | $0.45 | $0.90 | https://megatronica.cc/producto/cable-flexible-18-awg-negro-por-metros/
34 Cable Flexible | #18 AWG Verde por Metros | Para la puesta a tierra física. | 4 | $0.45 | $1.80 | https://megatronica.cc/producto/cable-flexible-18-awg-verde-por-metros/
35 FUSIBLE 10A | (Ref: V-0515) | Fusible de protección. | 1 | $0.20 | $0.20 | https://inselec.com.ec/store/inicio/1470-fusible-10a- ref-v-0515-.html
36 MAXIM | MAX7219 | Circuito integrado versátil que simplifica la tarea de controlar display de 7 segmentos y matrices de LED (Controla hasta 2 displays). | 2 | $2.50 | $5.00 | https://avelectronics.cc/producto/max7219/

37 Display de 4 | dígitos, 7 segmentos c/u, cátodo común | Dimensiones: 50,3mm X 19 mm X 8 mm | 3 | $1.99 | $5.97 | https://www.steren.com.ec/display-de-4-digitos-7- segmentos-c-u-catodo-comun.html
38 Boquilla de | latón E10 sin base | Boquillas E10 Socket P/Foco de Linterna 1-12V | 4 | $0.35 | $1.40 | https://www.vilconsa.com/viewdetalle.php?id_articulo 16701
39 | Foco miniatura de rosca, de 6,3 Volts y 1,57 Watts | Focos incandescentes que se iluminarán con la energía entregada por el panel. | 4 | $0.85 | $3.40 | https://www.steren.com.ec/foco-miniatura-de-rosca-de- 6-3-volts-y-1-57-watts.html
40 | SOPORT ES ESPACIA DORES SEPARA DORES DE LATON M3, M4 y M2.5 | Se necesitará 16, de longitud 30 mm y 16 de longitud 20 mm (para placas electrónicas en el doble fondo). También se necesitará 4 M4 para fijación del Arduino y 2 M2.5 para fijación del módulo reductor de voltaje. | 38 | $0.50 | $19.00 | https://roboticsec.com/producto/soportes-espaciadores-separadores-de-laton-m3/
41 TORNILL OS | DE LATON M3, M4 y M2.5 | Pernos de latón, cabeza redonda estrella, M3 Longitud de 5 mm. 32 de M3, 4 de M4 y 2 de M2.5 | 38 | $0.25 | $9.50 | https://roboticsec.com/producto/tornillos-de- laton-m3/
42 TUERCA DE | LATON M3, M4 y M2.5 | 32 de M3, 4 de M4 y 2 de M2.5 | 38 | $0.20 | $7.60 | https://roboticsec.com/producto/tuerca-de-laton- m3/
43 UNO R3 + | Cable Usb Atmega32 8p ARDUIN O | Tarjeta Uno R3 Arduino compatible + Cable Usb | 1 | $15.00 | $15.00 | https://megatronica.cc/producto/tarjeta-para-arduino-cable-usb-chip-desmontable/

44 Shield de | borneras para Arduino | Sirve para poder tener mejor acceso a los pines del Arduino, se dispone de entradas para los cables con el shield. | 1 | $6.50 | $6.50 | https://megatronica.cc/producto/shield-de-borneras-arduino-uno-montaje-riel-din/
45 Jack AC con | Portafusib le y Switch | • Material externo: plástico y metal. • Voltaje: 250V. • Corriente: 10A, AC. • Ajustar el tamaño del fusible (L * W): 5 mm x 20 mm. • Agujero en el diámetro de la cara superior: 3 mm. • Distancia del centro del agujero: 4cm. | 1 | $3.00 | $3.00 | https://megatronica.cc/producto/jack-ac-con- portafusible-y-ranura-para-switch/
46 FUENTE DE | PODER 12VDC 10 A | 12V 10A (120W) Dimensiones aproximadas Largo: 150 -200 mm Ancho: 90 -110 mm Altura: 39 - 42 mm. Escoger una media o pequeña. | 1 | $9.99 | $9.99 | https://roboticsec.com/producto/fuentes-de-poder-12vdc/
47 CONECT OR | CONVER TIDOR PLUG DC005 A BORNER A DE 2 PINES | Exclusivament e para alimentar el Arduino mediante el puerto Jack que se tiene disponible. | 1 | $0.80 | $0.80 | https://grupoelectrostore.com/shop/cables-plugs-y-conectores/conectores/conector-convertidor-plug- dc005-a-bornera-de-2-pines/

48 BASES | ADHESIV AS BLANCA S ( Ref: P-0355 ) | Para organización de cableado. | 15 | $0.21 | $3.15 | https://inselec.com.ec/store/inicio/2765-bases- adhesivas-blancas-ref-p-0355-.html
49 AMARRA | - 3MMX150 MM (funda de 100 unidades) | 1. Construcción de nailon 66 2. Bridas autoblocantes 3. TamaÑo: 3 x 150 mm | 1 | $2.10 | $2.10 | https://www.vilconsa.com/viewdetalle.php?id_articulo 19994
50 | Bornera de 2 pines azul | BORNERA 2 PIN 12X8MM AZUL | 8 | $0.54 | $4.32 | https://www.vilconsa.com/viewdetalle.php?id_articulo 18655
51 | Bornea de 3 pines azul | BORNERA 3 PIN 15X15MM TORNILLO PLANO | 2 | $0.30 | $0.60 | https://www.vilconsa.com/viewdetalle.php?id_articulo 13338
52 | Bornera de 4 pines azul | BORNERA 4PINES PITCH 5.00MM AZUL. En realidad, se usaría de 4 de 8 borneras. Pero se las uniría, necesitando 8 de 4 borneras. | 8 | $0.25 | $2.00 | https://www.vilconsa.com/viewdetalle.php?id_articulo 18318
53 | Sensor de voltaje y corriente ina219 | Se usa para el sensado del consumo energético de las cargas eléctricas. Sensa voltaje (hasta 32 26V) y corriente (hasta 3.2 A) | 1 | $6.30 | $6.30 | https://avelectronics.cc/producto/sen sor-de-corriente-dc-ina219/
54 Reductor de | voltaje LM2596 | Se usará para administrar los 12V que manda la fuente DC. | 1 | $3.00 | $3.00 | https://novatronicec.com/index.php/product/regulador-de-voltaje-dc-dc-lm2596/

55 | Base amarra | Sirve de organizadores para el cableado electrónico | 15 | $0.10 | $1.50 | https://www.vilconsa.com/viewdetalle.php?id_articulo=26 212
| | | | TOTAL | $268.57

10.CONCLUSIONES

En conclusión, el proyecto crea una representación visual de como un generador eólico a escala puede transformar energía cinética de las corrientes de aire a energía mecánica en la parte del interior del sistema de engranas y conectados al motor, enviados por un transformador para aumentar la tensión y, por último, la creación de energía eléctrica para que se use en diferentes cosas como, por ejemplo, prender focos, cargar aparatos electrónicos, etc.

También, este proyecto obtuvo un diseño funcional y eficiente, ya que, el proyecto se realizó a cabalidad y con resultados positivos en su funcionamiento y creación de mismo. Por lo que, es un generador eólico a escala produce aproximadamente 10 Vatios. No obstante, si se desea agrandar el diseño si es posible, pero en cambio ya hay que trabajar con energía alterna, ya que, son motores más grandes y tomar en cuenta otros factores como el uso de materiales ligeros y resistentes a los vientos para que puedan producir energía eléctrica con bajas corrientes de aire.

Para finalizar, el enfoque sobre educación ambiental para concientizar a la comunidad estudiantil y población en general sobre la importancia de buscar energía renovables y limpias para reducir el consumo de combustibles fósiles y la huella de carbono que las industrias producen en cantidades masivas anualmente.

11.RECOMENDACIONES
- Calibrar correctamente los competentes utilizados, es necesario que el voltaje que llega a los mismos esté en el rango adecuado de operación.
- Verificar si el espesor del doble fondo es el adecuado para soportar el peso de todos los componentes.
- Comprobar cual es la posición óptima del anemómetro, de tal manera que no obstruya el viento que llega a las hélices del generador.
- Utilizar otros métodos de sujeción aparte de los ya mencionados, porque es posible que se necesiten más conexiones en caso de implementar este proyecto.
- Utilizar rodamiento axial en las bases de los ejes para soportar una mayor carga axial, y en caso de que se lo requiera, mecanizarlo.
- Evaluar la posibilidad de usar un sensor de ultrasonido como método de medición de la velocidad del viento no invasivo.
- Colocar un acrílico transparente en el generador, para que se pueda visualizar el mecanismo de transmisión de potencia.

REFERENCIAS

[1] Duffie, J. and Beckman, W. (2013). "Solar Engineering of Thermal Processes." Wiley. ISBN: 978-0470873663
[2] Burton, T., et al. (2011). "Wind Resource and Energy Assessment." In Wind Energy Handbook, Wiley. doi: 10.1002/9781119994367.ch4
[3] Murcia, G., et al (2009). “Aplicación de un dispositivo de adquisición de datos a la evaluación del funcionamiento de pequeños generadores eólicos”. URL: http://sedici.unlp.edu.ar/bitstream/handle/10915/98138/Documento_completo.pdf-PDFA.pdf?sequence=1&isAllowed=y

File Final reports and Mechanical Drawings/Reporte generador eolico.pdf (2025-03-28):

PRÁCTICAS DE SERVICIO COMUNITARIO

PROYECTO:

INGENIERÍA PARA EL DESARROLLO DE PROTOTIPOS DIDÁCTICOS

PARA FORMACIÓN EDUCATIVA

PROGRAMA:

PROGRAMA DE VINCULACIÓN DE LA FIMCP (2023-2027)

TUTOR:

ZAMORA OLEA GEANCARLOS

ESTUDIANTES:

ESPIN LUMBANO ANGEL JOSUE

angelumb@espol.edu.ec

FONSECA MEDINA ANDRÉE GABRIEL

andgafon@espol.edu.ec

### 1. RESUMEN

A medida se continuamos desarrollando tecnologías y promoviendo políticas favorables, las energías renovables se están convirtiendo en la base de un futuro energético por ende en este proyecto tiene la finalidad de permitir la generación de equipos didácticos y amigables para estudiantes de diferentes niveles de educación, con ello en el informe de las ventajas, desventajas, oportunidades y mejoras del equipo.

### 2. INTRODUCCION

La energía renovable se ha convertido en un tema cada vez más relevante en todo el mundo debido a su impacto positivo en el medio ambiente y su potencial para satisfacer nuestras necesidades energéticas de manera sostenible. Las energías renovables son fuentes de energía que se obtienen de fuentes naturales que son inagotables o que se renuevan rápidamente, como la energía solar, eólica, hidroeléctrica, geotérmica y la biomasa.

A diferencia de los combustibles fósiles, cuya extracción y quema generan emisiones de gases de efecto invernadero y contribuyen al cambio climático, las energías renovables no emiten gases contaminantes durante su funcionamiento. Esto las convierte en una alternativa limpia y respetuosa con el medio ambiente, ayudando a reducir la contaminación del aire y mitigar el calentamiento global.

Además de su beneficio ambiental, las energías renovables también tienen un impacto positivo en la economía global. La transición hacia fuentes de energía renovable ha generado la creación de nuevos empleos en el sector, desde la fabricación y instalación de paneles solares y aerogeneradores hasta la operación y mantenimiento de parques eólicos y plantas solares. Estas inversiones en energías renovables también promueven la independencia energética, ya que reducen la dependencia de los combustibles fósiles importados.

En términos de acceso a la energía, las fuentes renovables pueden proporcionar soluciones a comunidades rurales o remotas que no tienen acceso a la red eléctrica convencional. La energía solar, por ejemplo, puede aprovecharse a través de paneles solares individuales o sistemas de microrredes, llevando electricidad a áreas que anteriormente dependían de fuentes contaminantes o que carecían de energía por completo.

Energía eólica
En [2] la definen a la energía eólica se refiere a la energía generada por el viento. Es una forma de energía renovable que aprovecha la fuerza cinética del viento para convertirla en energía eléctrica o mecánica. Se obtiene mediante la utilización de aerogeneradores, que son grandes estructuras equipadas con hélices o palas que giran cuando son impulsadas por el viento. La energía cinética del viento se transforma en energía mecánica al hacer girar las hélices, y luego esta energía mecánica se convierte en electricidad mediante un generador. La energía eólica es una fuente limpia y sostenible de energía que no produce emisiones de gases de efecto invernadero ni contribuye al calentamiento global.

En el proyecto de diseño de un generador de energía eólica, nuestro objetivo principal es crear una representación visual que muestre cómo se puede generar electricidad a partir del flujo del viento. Para lograr esto, nos hemos planteado dos objetivos específicos:

Diseño Funcional: El primer objetivo se enfoca en construir una maqueta que incluya molinos de viento que realmente giren y generen electricidad simulada cuando el viento los mueva. Esto ayudará a las personas a comprender de manera práctica cómo funciona la energía eólica.

Educación Ambiental: El segundo objetivo es utilizar un equipo como una herramienta educativa para enseñar a las personas sobre la importancia de la energía eólica y cómo contribuye a cuidar nuestro entorno. Queremos crear materiales y presentaciones informativas que expliquen cómo la energía eólica es una fuente de energía limpia y cómo puede ayudar a reducir la contaminación y el cambio climático. Nuestra meta final es concienciar a la comunidad sobre la importancia de las energías renovables.

### 3. DESCRICPIÓN PROTOTIPO ACTUAL

El generador de energía eólica a pequeña escala consta de varias etapas clave para la captura y conversión de la energía cinética del viento en electricidad:

- Sistema de Captura del Viento (Aspas y Eje del Motor): En la primera etapa, las aspas, diseñadas aerodinámicamente, están montadas en el eje del motor. Cuando el viento golpea estas aspas, generan un movimiento rotativo del eje.
- Sistema de Transmisión (Poleas Dentadas): Para aprovechar eficazmente el movimiento rotativo del eje, se utiliza un sistema de poleas dentadas. Esto permite aumentar la velocidad de rotación, optimizando la conversión de la energía cinética en electricidad.
- Generación de Viento: Para simular las condiciones de viento, se emplea un motor (drone). Este motor produce una corriente de aire que imita las fuerzas del viento, lo que permite evaluar el funcionamiento del generador en diferentes velocidades del viento.
- Sistema de eléctrico con medición de parámetros: El sistema eléctrico incluye sensores para medir diversas variables. Estos sensores registran la velocidad del viento, la potencia generada, el voltaje y el amperaje. También se han conectado focos de 5V como cargas eléctricas para ilustrar la producción de electricidad.

Este generador de energía eólica en miniatura consta de componentes esenciales para la captura, transmisión y conversión de la energía del viento en electricidad. Además, incorpora un sistema de medición eléctrica que permite visualizar en tiempo real datos para evaluar su rendimiento.


### 4. DISEÑO CONCEPTUAL

Dentro del diseño conceptual posee ciertas variaciones de componentes, este caso se tomó a consideración el funcionamiento de dispositivos eólicos en el mercado aerogeneradores verticales y horizontales.

- Diseño Conceptual uno: Generador de Eje Vertical
En este diseño, se utiliza un generador de eje vertical con tres aspas aerodinámicas montadas en un eje central. Las aspas están conectadas a un sistema de poleas dentadas que aumenta la velocidad de rotación del eje del motor. Para simular el viento, un motor se coloca estratégicamente para generar un flujo de aire hacia las aspas. El sistema eléctrico incorpora sensores de velocidad del viento, potencia, voltaje y amperaje, junto con luces incandescentes
como | cargas | eléctricas | para | visualizar | la | producción | de | electricidad.
- Diseño Conceptual dos: Aerogenerador de Eje Horizontal con Aspas

En este diseño, se utiliza un aerogenerador de eje horizontal con tres aspas largas y delgadas montadas en un eje horizontal. El viento natural impulsa las aspas, que están conectadas directamente a un generador eléctrico. Para complementar el viento natural y permitir pruebas controladas, se incorpora un motor que puede ajustar su velocidad para simular diferentes condiciones de viento. El sistema de medición eléctrica incluye sensores de velocidad del viento, potencia, voltaje y amperaje, así como luces incandescentes como cargas eléctricas para mostrar la generación de electricidad.

Ambos diseños conceptuales pueden servir como maquetas didácticas y funcionales para ilustrar los principios de generación de energía eólica y permitir experimentos prácticos con variables de viento controladas.

### 5. PROCESO DE DESARROLLO

### 5.1 Diseño mecánico:

### 5.1.1 Selección de desarrollo de aspas:

El diseño conceptual 1, que utiliza un generador de eje vertical con aspas y un motor para simular el viento, es menos complejo de construir que el diseño conceptual 2, que emplea un aerogenerador de eje horizontal. A continuación, se detallan las razones que sustentan la afirmación:

- Simplicidad del Diseño Mecánico:

En el diseño 1, el eje vertical es más sencillo de fabricar y montar que un sistema de eje horizontal. No se requiere una estructura de torre alta para elevar el generador y las aspas.

- Menos Componentes en Movimiento:

El diseño 1 implica menos componentes móviles, ya que las aspas giran alrededor de un eje vertical y no requieren un mecanismo de orientación complicado para seguir el viento. Esto reduce la complejidad y el potencial de problemas mecánicos.

- Facilidad de Ajuste del Motor

En el diseño 1, el motor se utiliza para simular el viento y puede ajustarse fácilmente para variar la velocidad del viento simulado. Esto permite una experimentación más controlada y sencilla en comparación con el diseño 2, que depende de la dirección natural del viento.

- Menor Tamaño y Espacio Requerido:

El diseño 1 ocupa menos espacio físico debido a la disposición vertical de las aspas y el generador. Esto lo hace más adecuado para entornos con espacio limitado y facilita su transporte y almacenamiento.

- Menos Requisitos de Mantenimiento:

Debido a su simplicidad y menos componentes en movimiento, el diseño 1 tiende a requerir menos mantenimiento y es más duradero en el tiempo.

Dado a su simplicidad mecánica, menor cantidad de componentes móviles y la posibilidad de controlar la velocidad del viento simulado de manera precisa. Esto lo convierte en una opción más asequible y accesible para propósitos educativos y experimentales.

Metodología:

1. Requisitos del Diseño
- Especificaciones del Generador: Comprende las especificaciones de tu generador eléctrico, incluyendo la potencia nominal, la velocidad de rotación y la tensión de operación. Esto te dará una idea de las características necesarias para las aspas.

- Velocidad del Viento Promedio: Determina la velocidad promedio del viento en el sitio donde se instalará el sistema de generación eólica. Esto afectará el diseño de las aspas.
2. Diseño de Aspas Darrieus-Savonius
- Longitud de las Aspas (Darrieus): Calcula la longitud de las aspas Darrieus en función de la velocidad del viento, la potencia deseada y el radio del rotor. Considera que las aspas Darrieus son curvas y se montan verticalmente.
- Diseño de Aspas Savonius: Determina las dimensiones de las aspas Savonius en función de la velocidad del viento y la potencia deseada. Las aspas Savonius son semicirculares y se montan horizontalmente.
3. Materiales y Construcción
- Materiales de las Aspas: Selecciona los materiales adecuados para las aspas. Pueden ser de fibra de vidrio, aluminio u otros materiales compuestos. Considera la durabilidad y la resistencia a la corrosión.
4. Diseño Aerodinámico
- Perfil Aerodinámico: Diseña el perfil aerodinámico de las aspas para maximizar la eficiencia y minimizar la resistencia al viento. Esto implica la forma y la curvatura de las aspas.
- Ángulo de Ataque: Calcula el ángulo de ataque óptimo para las aspas en función de la velocidad del viento y la geometría del rotor.
5. Fabricación y Montaje
- Fabricación de las Aspas: Construye las aspas de acuerdo con las especificaciones de diseño utilizando técnicas adecuadas de fabricación, como moldeo por inyección o fabricación manual.
- Montaje: Instala las aspas en el rotor o el sistema Darrieus-Savonius de manera que estén equilibradas y correctamente alineadas.
6. Pruebas y Optimización
- Pruebas de Rendimiento: Realiza pruebas de rendimiento en condiciones reales de viento para verificar que las aspas generen la potencia esperada.
- Ajustes: Realiza ajustes en el diseño o la geometría de las aspas si es necesario para optimizar la eficiencia y el rendimiento del sistema.
7. Mantenimiento y Monitoreo
- Mantenimiento: Establece un programa de mantenimiento regular para inspeccionar y mantener las aspas en buen estado de funcionamiento.
- Monitoreo: Utiliza sistemas de monitoreo para supervisar el rendimiento de las aspas y detectar cualquier problema o desgaste temprano.


### 5.1.2 Base del equipo

Metodología:

1. Diseño y Planificación: Antes de empezar, planifica las dimensiones de la base y dibuja un diseño. Considera el tamaño de las láminas de acrílico y cualquier carga que deba soportar.
2. Corte de los Tubos o Barras: Corta los tubos o barras según las dimensiones especificadas en tu diseño utilizando una sierra adecuada. Mide y marca con precisión antes de cortar.
3. Montaje de la Estructura: Ensámblala utilizando tornillos, tuercas y arandelas. Comienza desde la parte inferior y asegúrate de que la estructura esté nivelada. Utiliza un nivel para verificar la horizontalidad.
4. Preparación de las Láminas de Acrílico: Mide y marca las láminas de acrílico de acuerdo con las dimensiones de tu diseño. Corta el acrílico utilizando una sierra o cortador de vidrio para obtener cortes rectos y limpios.
5. Montaje de las Láminas de Acrílico: Coloca las láminas de acrílico sobre la estructura y asegúrate de que estén niveladas y alineadas correctamente. Usa clips o adhesivos adecuados para sujetarlas en su lugar.
6. Acabado y Ajustes: Revisa la base para asegurarte de que esté nivelada y que las láminas de acrílico estén seguras. Realiza ajustes si es necesario para lograr estabilidad y estética.
7. Limpieza y Mantenimiento: Limpia la base y las láminas de acrílico con un paño suave y agua jabonosa si es necesario. Mantén la base limpia y realiza el mantenimiento regularmente para prolongar su vida útil

### 5.1.3 Sistema de transmisión de potencia de las aspas al motor

Esta sección no es posible dimensionar directamente la relacion inicial final de la transmición por lo que se requiere que realizar pruebas del alcance que posee el motor.

Metodología:

1. Requisitos y Especificaciones :
- Determina los Requisitos de la Hélice: Define los requisitos de tu hélice, incluyendo el diámetro, el paso, la velocidad de rotación deseada y el sentido de giro (horario o antihorario).
- Especificaciones del Motor: Conoce las especificaciones de tu motor, como la velocidad nominal, la potencia de salida y el par motor máximo que puede proporcionar.
- Carga y Torque: Calcula la carga que la hélice ejercerá sobre el motor y el par de torsión (torque) necesario para girar la hélice a la velocidad deseada.
2. Selección de Materiales y Tipo de Engranajes

- Tipo de Engranajes: Elige entre engranajes rectos, helicoidales, cónicos u otros tipos, dependiendo de las necesidades de tu sistema y la disposición de los componentes.
- Materiales: Seleccione los materiales adecuados para los engranajes para garantizar la durabilidad y minimizar el desgaste. El acero y otros metales son comunes, pero también se utilizan plásticos de alta resistencia.
3. Cálculos de Diseño
- Relación de Transmisión: Calcula la relación de transmisión necesaria para igualar la velocidad de la hélice a la velocidad nominal del motor. Utiliza la fórmula: Relación de transmisión = Velocidad del motor / Velocidad de la hélice.
- Módulo y Paso: Determina el módulo de los engranajes (tamaño de los dientes) y el paso de los dientes para que coincidan con la relación de transmisión y el par requerido. Esto involucra cálculos específicos dependiendo del tipo de engranajes seleccionados.
- Número de Dientes: Calcula el número de dientes necesarios para los engranajes para que funcionen correctamente y distribuyan la carga de manera uniforme. Esto se relaciona con el módulo y la relación de transmisión.
- Diámetros y Ancho de los Engranajes: Determina el diámetro de los engranajes y su ancho para adaptarse al sistema y garantizar una distribución adecuada de la carga.
4. Diseño de Ejes y Soportes
- Diseño de Ejes: Diseña los ejes que sostendrán los engranajes y se conectarán al motor y a la hélice. Considera su resistencia y el método de sujeción.
- Soportes y Rodamientos: Integra soportes y rodamientos para asegurar una operación suave y minimizar la fricción en los ejes.
5. Simulación y Verificación
- Software de Simulación: Utiliza software de simulación de engranajes para verificar el diseño y evaluar su funcionamiento bajo diferentes condiciones de carga y velocidad.
- Prototipo o Pruebas: Si es posible, crea un prototipo o realiza pruebas en el mundo real para validar el rendimiento y la eficiencia del sistema de engranajes.
6. Fabricación y Montaje
- Fabricación: Fabrica los engranajes, ejes y otros componentes de acuerdo con las especificaciones de diseño.
- Montaje: Ensambla el sistema de engranajes en la configuración adecuada, asegurándote de que todo esté alineado y ajustado correctamente.
7. Pruebas y Ajustes Finales
- Pruebas de Carga: Realiza pruebas de carga para asegurarte de que el sistema de engranajes funcione según lo previsto bajo diferentes condiciones de carga y velocidad.
- Ajustes: Si es necesario, realiza ajustes finos en la configuración de los engranajes para optimizar el rendimiento y la eficiencia.
8. Mantenimiento y Monitoreo
- Mantenimiento: Establece un programa de mantenimiento regular para garantizar que el sistema de engranajes funcione de manera confiable

### 5.2 Diseño eléctrico:

Para el diseño eléctrico se tomaron a consideraron el uso de dispositivos corriente continua para la sección de generador de viento. Por lo que se tiene que tener en cuenta el uso de para receptar la energía mecánica en motores de corriente continua como generadores eléctricos y para la generación de viento un motor de corriente continua con imanes permanentes (motor de drones).

A continuación, se realiza una comparativa entre la selección de motores y la alimentación electrónica del sistema:

### 5.2.1 Motores DC como Generadores:

- Simplicidad de Conexión: Los motores DC se pueden utilizar directamente como generadores al conectarlos mecánicamente a las aspas. Esta simplicidad de conexión facilita su implementación en sistemas de generación eólica caseros.
- Control Preciso de la Velocidad: Los motores DC permiten un control preciso de la velocidad de rotación, lo que es ventajoso para ajustar la generación de energía en función de las condiciones del viento. Esto puede aumentar la eficiencia en comparación con los motores AC que funcionan a una frecuencia fija.
- Eficiencia en Bajas Velocidades de Viento: Los motores DC pueden generar electricidad a bajas velocidades de viento, lo que los hace adecuados para ubicaciones con vientos variables.
- Menor Requerimiento de Electrónica: Los motores DC suelen requerir menos componentes electrónicos para la conversión de energía en comparación con los motores AC, lo que puede simplificar el sistema.

### 5.2.2 Motores AC como Generadores:

- Mayor Eficiencia a Velocidades Altas: Los motores AC, como los generadores síncronos de imanes permanentes, tienden a ser más eficientes a altas velocidades de viento. Esto puede resultar en una mayor producción de energía en ubicaciones con vientos fuertes y constantes.
- Mayor Escalabilidad: Los sistemas de generación eólica comercial a gran escala a menudo utilizan motores AC debido a su capacidad para escalarse fácilmente y generar grandes cantidades de electricidad.
- Requiere Inversores: Los motores AC generan corriente alterna, por lo que se necesita un inversor para convertir la corriente en continua para su uso en la red eléctrica o en dispositivos de corriente continua. Esto puede agregar costos y complejidad al sistema.
- Menos Control de Velocidad: Los motores AC pueden ser menos flexibles en términos de control de velocidad en comparación con los motores DC. Esto puede limitar la adaptabilidad del sistema a condiciones variables de viento.

### 5.3.3 Definición de redes eléctricas y mediciones del sistema

1. Identificación de Requisitos y Componentes

- Determina los Requisitos del Sistema: Comprende las necesidades de alimentación de corriente continua para los equipos y las mediciones requeridas para los motores. Esto incluye voltaje, corriente, tipo de sensores, etc.
- Selección de Componentes: Identifica y selecciona los componentes necesarios, como fuentes de alimentación DC, cables, sensores, controladores, y equipos de medición.
2. Diseño de Alimentación DC
- Fuente de Alimentación DC: Elige la fuente de alimentación DC adecuada que cumpla con los requisitos de voltaje y corriente para los equipos. Asegúrate de que sea capaz de proporcionar la potencia necesaria.
- Distribución de Energía: Diseña un sistema de distribución de energía que incluya reguladores de voltaje, interruptores y fusibles para garantizar un suministro de energía confiable y seguro a los equipos.
3. Cableado y Conexiones
- Selección de Cables: Selecciona cables de corriente continua de calibre adecuado para minimizar la pérdida de voltaje y garantizar una conexión segura y confiable.
- Conexiones Correctas: Conecta los equipos a la fuente de alimentación DC siguiendo las polaridades correctas y asegurándote de que todas las conexiones estén bien apretadas.
4. Integración de Sistemas de Medición
- Sensores y Transductores: Instala sensores y transductores adecuados en los motores para medir variables como la velocidad, la temperatura, la corriente y el voltaje.
- Cableado de Sensores: Conecta los sensores a los controladores o instrumentos de medición utilizando cables adecuados y siguiendo las especificaciones del fabricante.
5. Configuración de Controladores e Instrumentación
- Programación de Controladores: Configura y programa los controladores para adquirir y procesar datos de los sensores, y para controlar el funcionamiento de los motores según sea necesario.
- Calibración: Realiza la calibración de los sistemas de medición para asegurarte de que las lecturas sean precisas y se correspondan con las condiciones reales.
6. Pruebas y Validación
- Pruebas Iniciales: Realiza pruebas iniciales para asegurarte de que los equipos DC estén funcionando correctamente y de que los sistemas de medición estén proporcionando datos precisos.
- Ajustes y Optimización: Realiza ajustes en la configuración o en los controladores según sea necesario para optimizar el rendimiento del sistema.
7. Monitoreo y Mantenimiento
- Monitoreo Continuo: Implementa un sistema de monitoreo continuo para supervisar el funcionamiento de los equipos DC y los sistemas de medición.
- Mantenimiento Regular: Establece un programa de mantenimiento preventivo para asegurarte de que todos los componentes estén en buen estado y para reemplazar cualquier componente defectuoso.
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

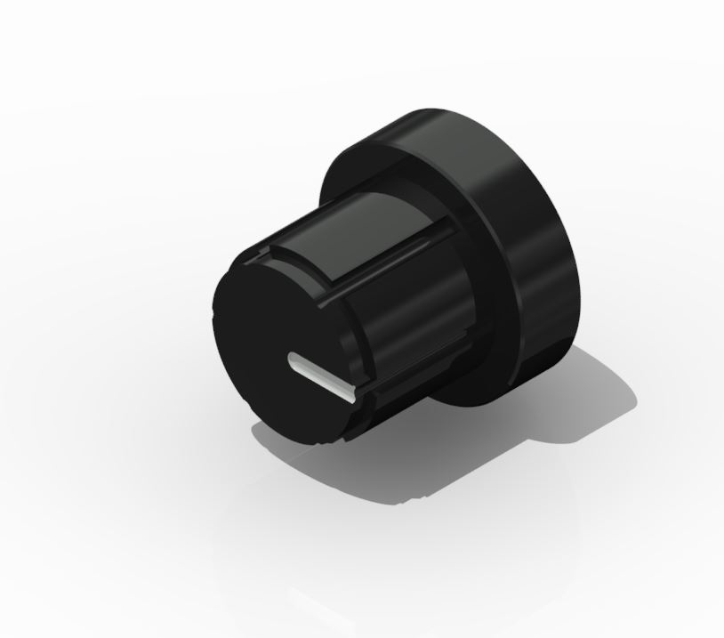
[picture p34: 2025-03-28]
Final reports and Mechanical Drawings/potentiometer Knob.jpg

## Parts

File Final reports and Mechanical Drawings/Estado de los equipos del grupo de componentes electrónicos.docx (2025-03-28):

PRÁCTICAS DE SERVICIO COMUNITARIO

PROYECTO:

INGENIERÍA PARA EL DESARROLLO DE PROTOTIPOS DIDÁCTICOS PARA FORMACIÓN EDUCATIVA

PROGRAMA:

PROGRAMA DE VINCULACIÓN DE LA FIMCP (2023-2027)

TUTOR:

ZAMORA OLEA GEANCARLOS

ESTUDIANTES:

ESPIN LUMBANO ANGEL JOSUE

angelumb@espol.edu.ec

FONSECA MEDINA ANDRÉE GABRIEL

andgafon@espol.edu.ec

## 1. RESUMEN

A medida se continuamos desarrollando tecnologías y promoviendo políticas favorables, las energías renovables se están convirtiendo en la base de un futuro energético por ende en este proyecto tiene la finalidad de permitir la generación de equipos didácticos y amigables para estudiantes de diferentes niveles de educación, con ello en el informe de las ventajas, desventajas, oportunidades y mejoras del equipo.

## 2. INTRODUCCION

La energía renovable se ha convertido en un tema cada vez más relevante en todo el mundo debido a su impacto positivo en el medio ambiente y su potencial para satisfacer nuestras necesidades energéticas de manera sostenible. Las energías renovables son fuentes de energía que se obtienen de fuentes naturales que son inagotables o que se renuevan rápidamente, como la energía solar, eólica, hidroeléctrica, geotérmica y la biomasa.

A diferencia de los combustibles fósiles, cuya extracción y quema generan emisiones de gases de efecto invernadero y contribuyen al cambio climático, las energías renovables no emiten gases contaminantes durante su funcionamiento. Esto las convierte en una alternativa limpia y respetuosa con el medio ambiente, ayudando a reducir la contaminación del aire y mitigar el calentamiento global.

Además de su beneficio ambiental, las energías renovables también tienen un impacto positivo en la economía global. La transición hacia fuentes de energía renovable ha generado la creación de nuevos empleos en el sector, desde la fabricación y instalación de paneles solares y aerogeneradores hasta la operación y mantenimiento de parques eólicos y plantas solares. Estas inversiones en energías renovables también promueven la independencia energética, ya que reducen la dependencia de los combustibles fósiles importados.

En términos de acceso a la energía, las fuentes renovables pueden proporcionar soluciones a comunidades rurales o remotas que no tienen acceso a la red eléctrica convencional. La energía solar, por ejemplo, puede aprovecharse a través de paneles solares individuales o sistemas de microredes, llevando electricidad a áreas que anteriormente dependían de fuentes contaminantes o que carecían de energía por completo.

Energía eólica

En [2] la definen a la energía eólica se refiere a la energía generada por el viento. Es una forma de energía renovable que aprovecha la fuerza cinética del viento para convertirla en energía eléctrica o mecánica. Se obtiene mediante la utilización de aerogeneradores, que son grandes estructuras equipadas con hélices o palas que giran cuando son impulsadas por el viento. La energía cinética del viento se transforma en energía mecánica al hacer girar las hélices, y luego esta energía mecánica se convierte en electricidad mediante un generador. La energía eólica es una fuente limpia y sostenible de energía que no produce emisiones de gases de efecto invernadero ni contribuye al calentamiento global.

Energía solar

La energía solar según [1] se refiere a la energía obtenida a partir de la radiación del sol. Se basa en la conversión directa de la luz solar en electricidad o en energía térmica. Para aprovechar la energía solar, se utilizan dispositivos como paneles solares o colectores solares. Los paneles solares fotovoltaicos contienen células fotovoltaicas que capturan la luz solar y la convierten en electricidad mediante el efecto fotovoltaico. Por otro lado, los colectores solares térmicos utilizan la radiación solar para calentar un fluido que puede utilizarse para generar calor o producir agua caliente. La energía solar es una fuente abundante, renovable y respetuosa con el medio ambiente, ya que no produce emisiones contaminantes durante su funcionamiento.

## 3. DESCRICPIÓN GENERAL DE EQUIPOS

MEDIDAS GENERALES

Módulo eólico: 27.5cm x27.5cm x30cm

Módulo solar: 27.5cm x27.5cm x30cm

MODULO EÓLICO

Funcionamiento y caracterización

El módulo eólico, ilustración 1, posee un grupo de componentes se divide en dos particularmente, la primera es un componente rectangular, en la ilustración 3, con la finalidad de restringir planar con movilidad lineal de un ventilador por que se acopla por medio de pernos y tuercas. La segunda parte, en la ilustración 2, a nivel eléctrico consta de un módulo de voltaje el cual permite recolectar una estimación energética en tiempo real en función del desplazamiento rotacional de las aspas por diferentes flujos de aire producido por el ventilador, adicionalmente esta posee una base trapezoidal y posee una restricción planar-movilidad linear.

Componentes:

- Estructura en forma rectangular
- Estructura aerodinámica
- Batería de 9 V
- Motor de corriente DC
- Interruptor
- Puerto de carga

MODULO SOLAR

Es un módulo de energía solar, ilustración 4, que consta con dos partes, unan de control y otra de potencia. Ambas partes el poseen una estructura hecha con PLA y construida con una impresora 3D, y están conectadas por medio de conexión directa(cables). La primera parte corresponde a al seguidor de luz, a nivel mecánico posee con 3 ejes de movilidad el cual se lo proporcionan 2 servomotores, adicionalmente posee sensores lumínicos (resistencias fotovoltaicas) con la finalidad de detectar la posición de la luz. A nivel eléctrico este consta de un panel solar y una base rotatoria, conectada a un sistema de adquisición y control de datos. En la segunda parte posee un controlador para el seguidor de luz y a un sistema eléctrico posee la posibilidad de dos modos: uno de ellos seguir la luz automáticamente la fuente de luz cercana y el otro modo corresponde al control de servomotores de manera independiente con dos perillas(potenciómetros). Adicionalmente esta posee una pantalla LCD con la capacidad de verificar los datos recolectados del cirquito de potencia. Esta tiene a su vez una batería independiente recargable y un cargador.

Componentes:

- Dos servomotores y cables
- Panel solar
- 4 fotorresistencias y cables
- Estructura mecánica (2 fija, revoluta, revoluta, mecanismo de 2 barras)
- 4 ventosas

## 4. PRIMERAS IMPRESIONES

Módulo solar (primera)

- Se desplazan con facilidad la estructuras cuando no el sistema no está encendido
- Mala presentación a nivel de pegamentos, cables sueltos, vista de cables y vista de componentes
- El peso es amigable con el usuario.
- No posee señalización eléctrica, ni mecánico.

Módulo solar (segunda)

- No posee señalización eléctrica, ni mecánico.
- Mala presentación a nivel de pegamentos, cables sueltos, vista de cables y vista de componentes.
- No es posible abrir la caja, no hay mecanismo para tener una buena reparación.
- Peso no tan amigable con el usuario.

Módulo eólico (primera)

- No posee un deslizamiento fácil para la modificación cantidad de flujo y ángulo de precisión.
- Peso amigable con el usuario.

Módulo eólico (segunda)

- Estructuras dijo
- mala presentación (suciedad, cables sueltos, vista de cables, vista de compones)
- El peso es amigable con el usuario

## 5. ESTADO DE LOS EQUIPOS

Equipo solar: no está funcional del todo, partes eléctricas poco comprometidas con funcionamiento invertido, este no sigue la luz en control automático (se aleja de la luz).

Equipo eólico: no está funcional, no hay forma de verificarlo.

## 6. POSIBLES MEJORAS

Módulo solar (primera)

- Realizar una sola línea de cables que no estén a la vista
- Hacer piezas con la finalidad de esconder los componentes mostrados.
- Cambiar el tipo de junto sobre las resistencias.
- Cambiar el tipo de servomotor, modificar el dimensionamiento, pero pierde potencia.

Módulo solar (segunda)

- Inserciones de tapa, diseño mecánico
- Compactar componentes.
- Señalización.
- Dimensionar para una mejor inserción de juntas electrónicas

Módulo eólico (primera)

- Inserciones de tapa, diseño mecánico
- Compactar componentes.
- Señalización (que hace, tipo de fuente, etc)
- Dimensionar para una mejor inserción de juntas electrónicas

Módulo eólico (segunda)

- Realizar una sola línea de cables que no estén a la vista
- Hacer piezas con la finalidad de esconder los componentes mostrados.
- Soldar o dejar una estructura para la parte eléctrica
- No posee tapa o protección ELECTRONICA

## 7. PROPUESTAS DE DISEÑO

MODULO EÓLICO

Para el caso de este módulo didáctico, se planteó rehacer el modelo, o al menos la mayor parte de este, por lo anterior mencionado, a continuación, se presentan distintas propuestas de diseño que se espera implementar:

1. Incorporación de una veleta en la parte superior de las aletas, para poder mostrar la dirección que posee el viento.

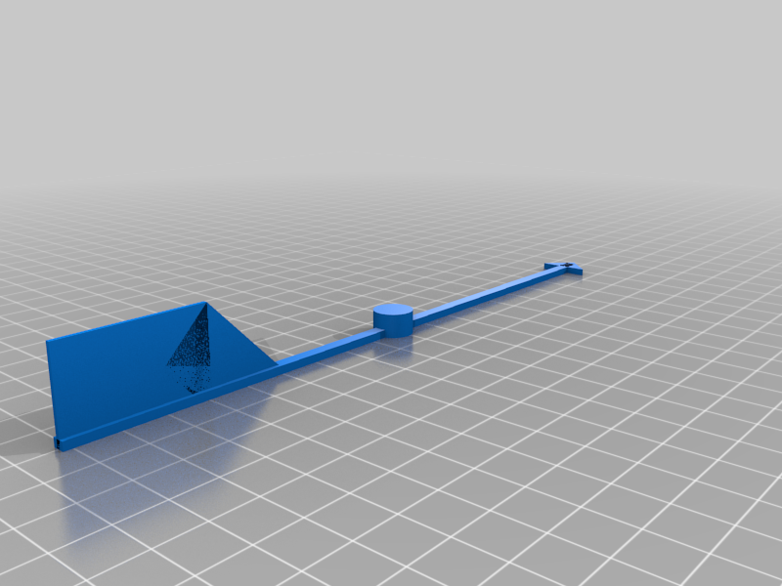
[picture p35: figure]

Ilustración 1 Veleta, referencia: https://www.stlfinder.com/model/wind-direction-compass-RDtXF9rr/4359053/

2. Rediseño del módulo para que se pueda utilizar un Arduino como microcontrolador, para así indicar la velocidad del viento.

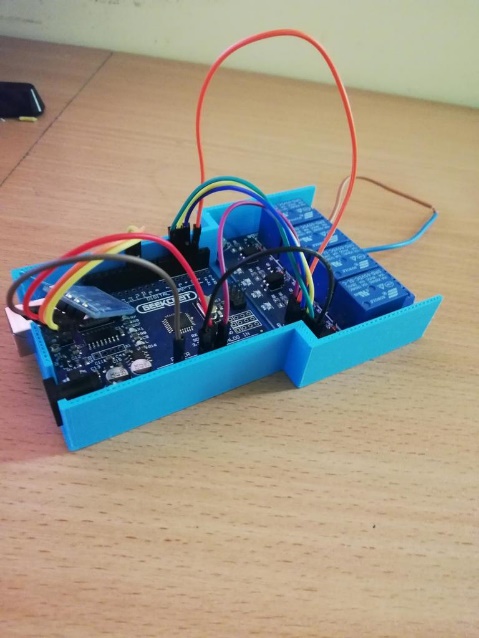
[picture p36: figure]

Ilustración 2 Espacio para Arduino https://www.stlfinder.com/model/arduino-O6bhWPzQ/2071768/

3. Aleta con forma semicircular, separa de la veleta, para poder cuantificar la cantidad de viento que recibe el dispositivo, en base a la dirección del viento.

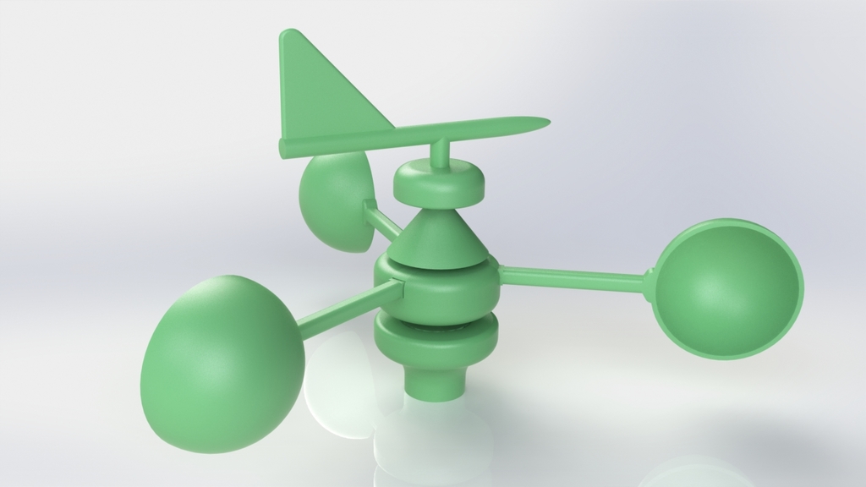
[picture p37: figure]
Card image

Ilustración 3 Aleta y Veleta separados. Referencia: https://www.stlfinder.com/model/wind-gauge-with-direction-indicator-88tjXZeJ/4042364/

4. Turbinas eólicas verticales, generalemente este posee una eficiencia mayor a los generadores eólicos horizontales. Permite adquirir flujo de aire en cuaquier dirección

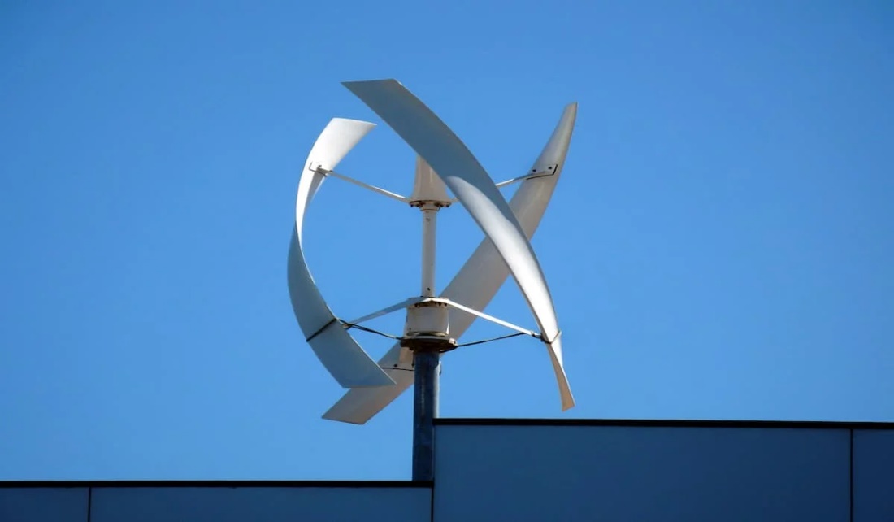
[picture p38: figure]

Ilustración 4 Aerogenerador vertical Referencia: https://www.totalenergies.es/es/pymes/blog/turbinas-eolicas-verticales-beneficios-y-diferencias

5. Modelo de aerogenerador doméstico silencioso, LIAM F1. Es capa de recibir flujo aire que ingresa alcanza una potencia decente en casi todas las direcciones del movimiento que posee la base

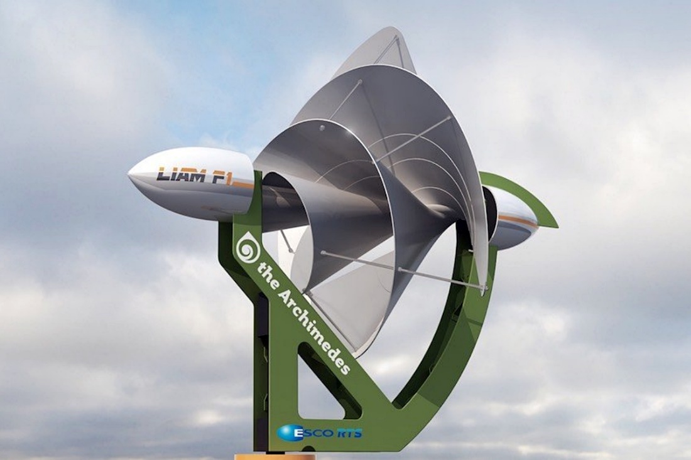
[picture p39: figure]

Ilustración 5 Aerogenerador vertical Referencia: https://www.motor.es/noticias/oferta-citroen-c3-you-202395711.html

6. Implementación de base giratoria en caso de seleccionar algún tipo de aerogenerador de tipo horizontal

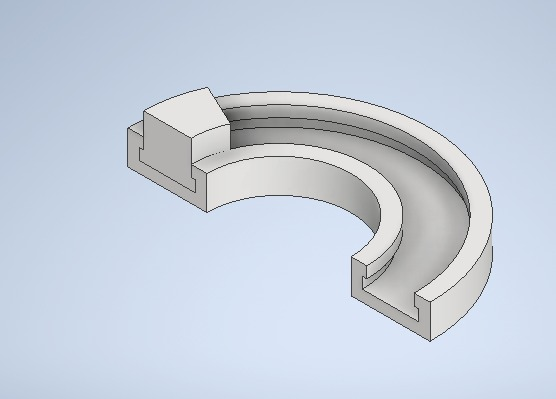
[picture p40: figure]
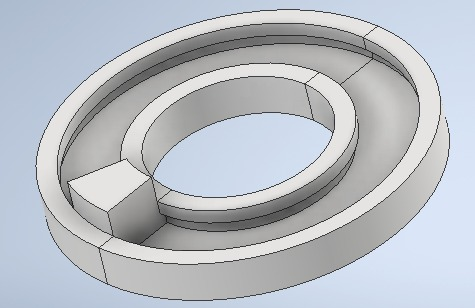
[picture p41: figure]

Ilustración 6 Base para Aerogenerador vertical

7. Implementación de pantalla LCD con la finalidad de mostrar datos de voltaje, amperaje, porcentaje de trabajo en un tiempo con respeto a la potencia teórica máxima.

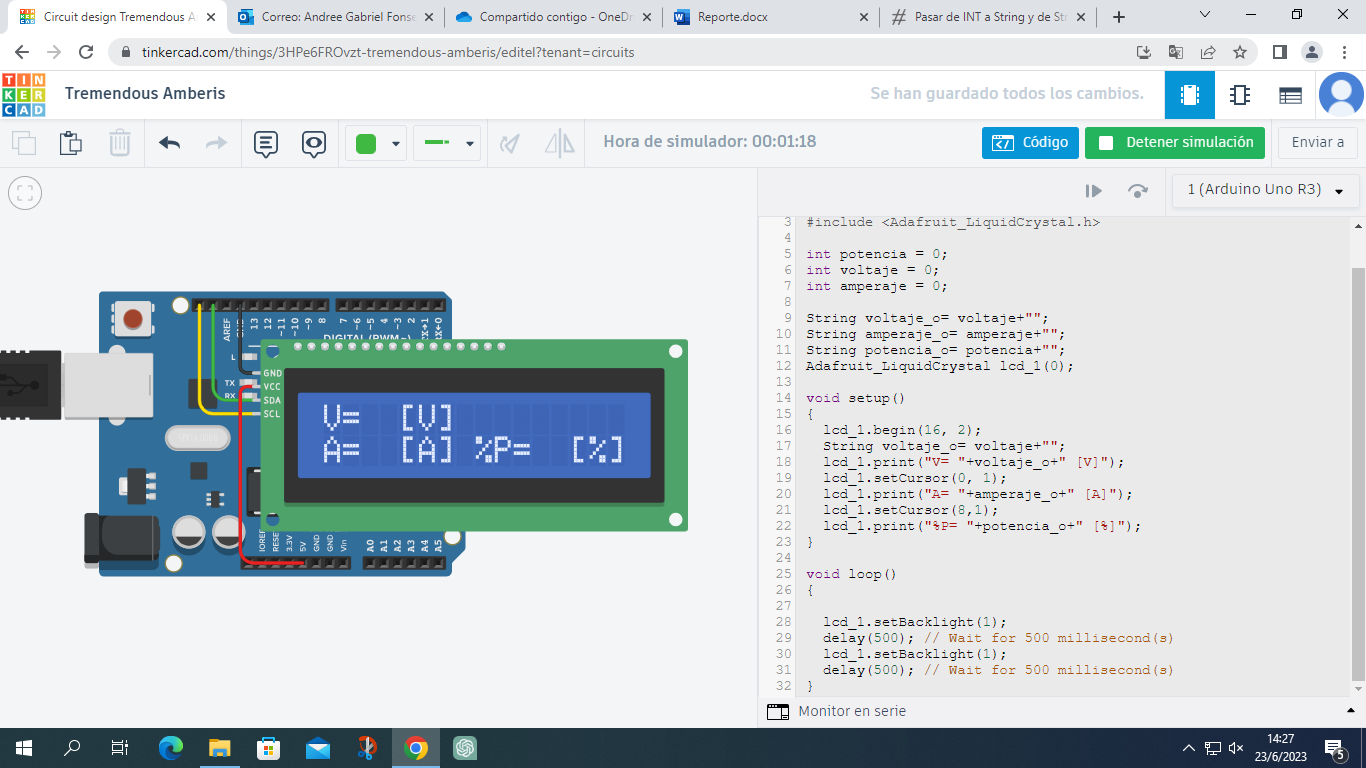
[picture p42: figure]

Ilustración 7 Pantalla LCD con datos relevantes del generador

MODULO SOLAR

## 8. PROTOTIPADO


Ilustración 8 Prototipo del módulo eólico con sus partes


Ilustración 9 Esquema general del prototipo del módulo eólico

## 9. ANEXOS (FOTOS DE LOS EQUIPOS)


Ilustración 10 Módulo de energía eólica


Ilustración 11 Módulo de voltaje


Ilustración 12 Base rectangular


Ilustración 13 Módulo de energía solar


Ilustración 14 Pines de entrada del módulo de energía solar


Ilustración 15 Cirquito de potencia, seguidor de luz.

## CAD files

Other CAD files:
Final reports and Mechanical Drawings/ANSI B18.3.1M - M2x0,4 x 30(1).ipt

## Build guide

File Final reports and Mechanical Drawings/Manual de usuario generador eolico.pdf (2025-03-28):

## Generador eólico

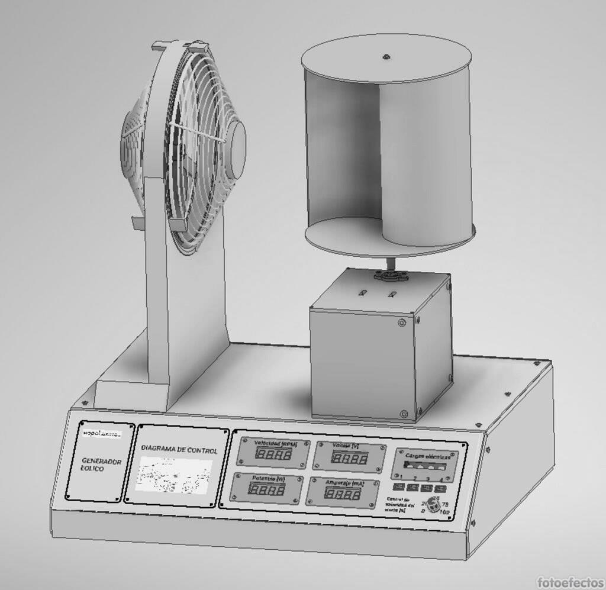
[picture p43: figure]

### Manual de usuario

### Dispositivo didáctico de generador eólico

## Contenido

Esquema de armado y nombre de las piezas Esquema del ventilador

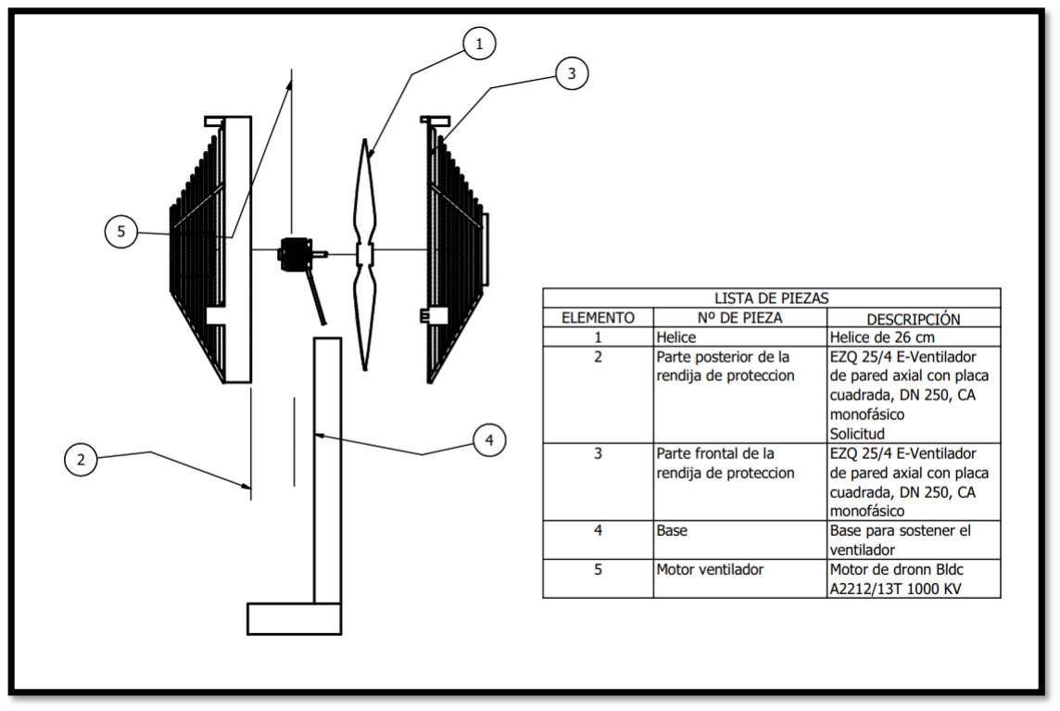
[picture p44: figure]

Instrucciones de armado
1. Colocar el motor bldc en la apertura que se encuentra en la parte posterior de la rendija de protección.
2. Colocar el cableado del motor en la prensa estopa ubicada en el chasis.
3. Insertar las aspas de 26 cm en el eje del motor.
4. Juntar la parte posterior y frontal de la rendija de protección con pernos.
5. Insertar la base del ventilador en la rendija de protección mediante una conexión con pernos
6. Empernar la base del ventilador con el chasis del módulo didáctico.

Mantenimiento
- En caso de obstruirse el giro del ventilador por la cantidad de polvo presente en el equipo, desarmar el mismo, y con un paño limpio y seco, limpiar las aspas del ventilador y el motor para eliminar el polvo acumulado. Asegurarse de desconectar el ventilador de cualquier fuente de alimentación antes de realizar el mantenimiento.
- Revisar periódicamente los pernos que unen las partes de la rendija de protección, la base del ventilador y el chasis del módulo didáctico. Asegurarse de que estén apretados y en buen estado. Apriételos si es necesario.

- Inspeccionar el cableado del motor para detectar posibles daños o desgaste. Si encuentra alguna anomalía, desconecte el ventilador de la fuente de alimentación y reemplace el cableado defectuoso.
- Mantener el área alrededor del ventilador libre de obstrucciones y objetos que puedan interferir con el flujo de aire.
- Si el ventilador presenta ruidos anormales, apague inmediatamente la alimentación y realice una inspección visual para identificar la causa. Puede ser necesario ajustar las aspas o lubricar el motor si es apropiado según las especificaciones del fabricante.
- Evite exponer el ventilador a condiciones extremas de temperatura o humedad que puedan afectar su funcionamiento.
- Realice un mantenimiento preventivo regular, al menos una vez al año, para garantizar un rendimiento óptimo y una vida útil prolongada del ventilador.

Panel Frontal: Instrucciones de Armado

El panel frontal es una parte importante de su generador eólico y contiene componentes como displays de LEDs de 7 segmentos, un potenciómetro, 4 focos incandescentes y 4 switches. A continuación, se detallan las instrucciones para ensamblar y conectar el panel frontal:

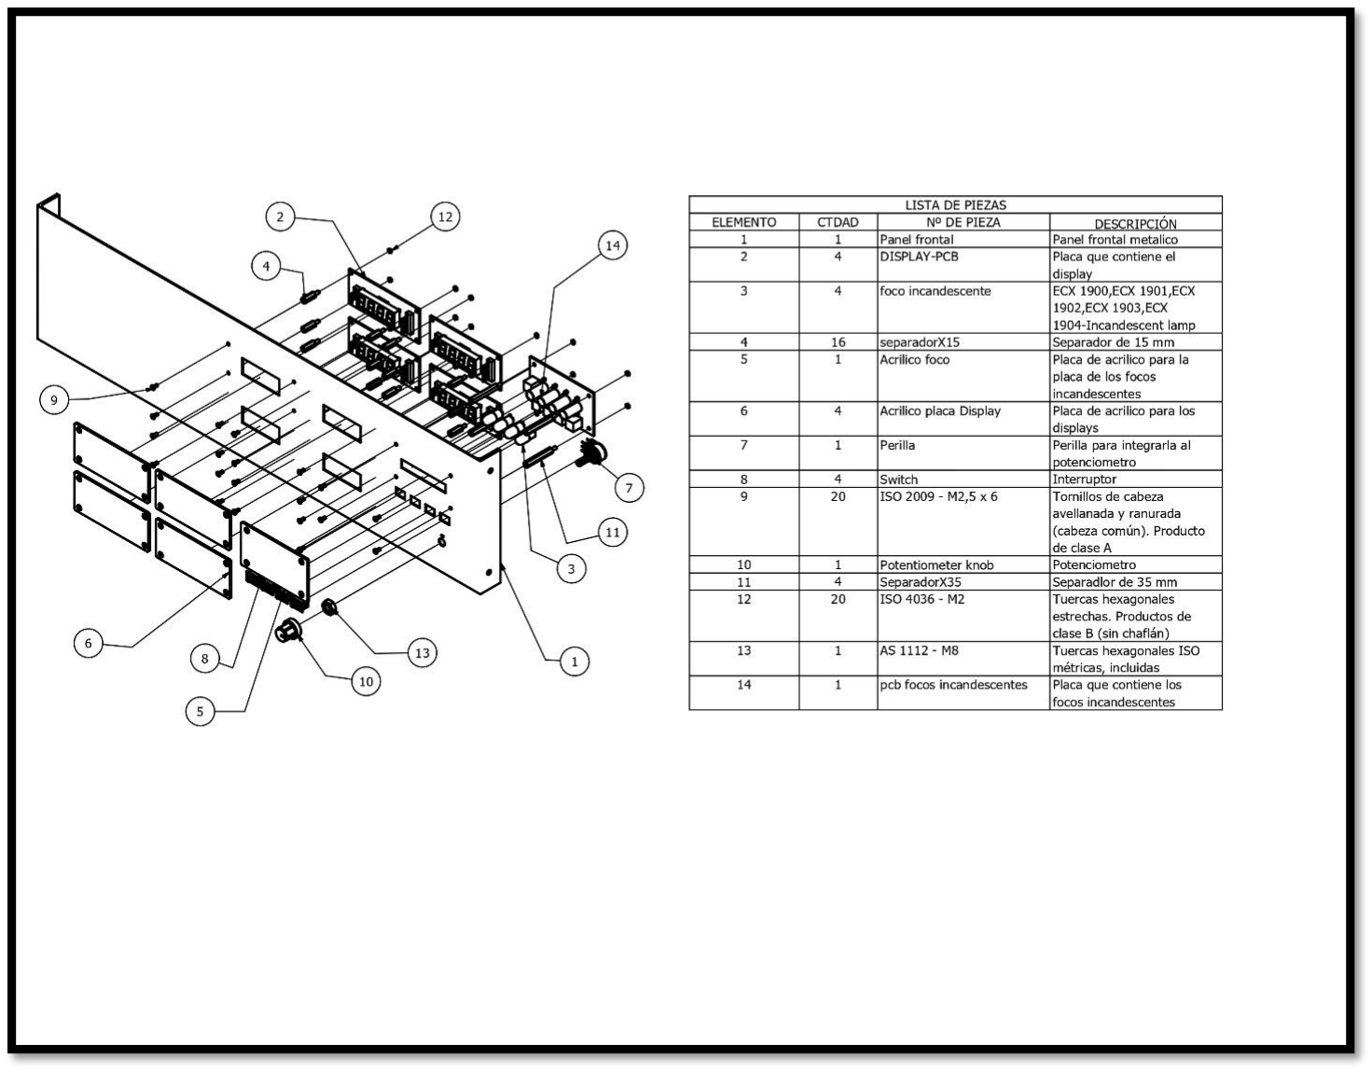
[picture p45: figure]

Materiales necesarios (lista de verificación):

- Panel frontal con aberturas para displays, potenciómetro, focos y switches.
- Displays de LEDs de 7 segmentos (4 unidades).
- Potenciómetro.
- Focos incandescentes (4 unidades).
- Switches (4 unidades).
- Herramientas básicas (destornilladores, alicates, etc.) según sea necesario.

- Elementos adicionales específicos de su diseño (cables, conectores, etc.).

Pasos de ensamblaje:

1. Displays de LEDs de 7 Segmentos:
- Inserte cada display de LEDs de 7 segmentos en las aberturas designadas en el panel frontal.
- Asegúrese de que estén correctamente alineados y asegurados en su lugar.
2. Potenciómetro:
- Monte el potenciómetro en la ubicación deseada en el panel frontal.
- Asegúrese de que el potenciómetro esté firmemente sujeto y que el eje del potenciómetro sea accesible desde el exterior del panel frontal.
3. Focos Incandescentes:
- Inserte los focos incandescentes en las aberturas diseñadas en el panel frontal.
- Asegúrese de que estén bien ajustados en su lugar.
4. Switches:
- Monte los switches en las ubicaciones deseadas en el panel frontal.
- Asegúrese de que los switches estén correctamente fijados y que sus actuadores sean accesibles desde el exterior del panel frontal.
5. Cableado:
- Conecte los cables desde los displays de LEDs de 7 segmentos, el potenciómetro, los focos incandescentes y los switches a los componentes internos correspondientes dentro del chasis (Arduino u otros componentes relevantes).
- Asegúrese de que los cables estén bien conectados y que no haya conexiones sueltas.
6. Organización: Organice los cables de manera ordenada para evitar enredos y asegúrese de que estén bien sujetos y protegidos contra daños.

Mantenimiento del Panel Frontal:

El mantenimiento regular del panel frontal es importante para garantizar su funcionamiento eficiente y durabilidad. A continuación, se detallan algunas pautas de mantenimiento:

1. Inspección Visual Regular: Realice inspecciones visuales regulares del panel frontal para identificar cualquier signo de desgaste, daño o componentes sueltos. Verifique que los displays de LEDs, el potenciómetro, los focos incandescentes y los switches estén en buen estado.
2. Funcionalidad de los Componentes: Verifique periódicamente que los displays de LEDs funcionen correctamente, que el potenciómetro se gire suavemente y que los focos incandescentes y los switches respondan como se espera. Reemplace los componentes defectuosos según sea necesario.
3. Limpieza: Mantenga el panel frontal limpio de polvo y suciedad que puedan obstruir el funcionamiento de los componentes. Limpie las superficies exteriores con un paño limpio y seco.
4. Verificación de Conexiones: Revise las conexiones de cables entre el panel frontal y los componentes internos del generador eólico. Asegúrese de que estén bien conectadas y en buen estado. Apriete cualquier conexión suelta.

Siguiendo estas instrucciones de armado y mantenimiento, podrá ensamblar y mantener eficazmente el panel frontal de su generador eólico, incluyendo los displays de LEDs, el potenciómetro, los focos incandescentes y los switches. Esto garantizará un funcionamiento óptimo y seguro de su dispositivo en el tiempo.

Chasis: Instrucciones de Armado

El chasis es una parte fundamental de su generador eólico y debe estar correctamente ensamblado para garantizar su funcionamiento eficiente y seguro. A continuación, se detallan las instrucciones para ensamblar el chasis:

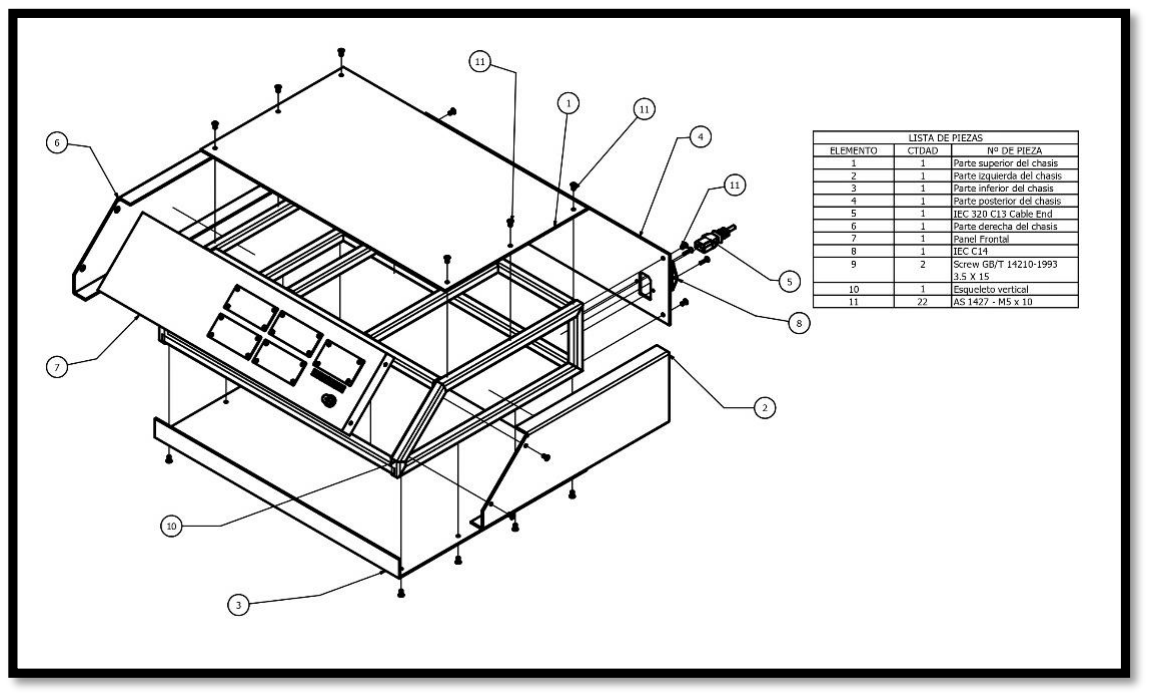
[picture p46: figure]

Materiales necesarios (lista de verificación):

- Esqueleto de tubo de perfil de acero.
- Paredes de chapa metálica de acero.
- Herramientas básicas (llave, destornilladores, etc.) según sea necesario.
- Elementos adicionales específicos de su diseño (soportes, sujetadores, etc.).

Pasos de ensamblaje:

1. Coloque el esqueleto de tubo de perfil de acero en una superficie plana y nivelada, de manera que esté listo para recibir las partes adicionales.
2. Fije las paredes de chapa metálica de acero al esqueleto de tubo de perfil de acero. Use los sujetadores adecuados para asegurar que las paredes estén firmemente unidas al esqueleto.

3. Asegúrese de que el chasis esté estable y bien equilibrado. Verifique que todas las partes estén aseguradas correctamente y que no haya partes sueltas o inestables.
4. Instale los componentes internos, como el motor BLDC (Brushless DC), la PCB para aumentar el amperaje, el Arduino y el power supply de 12 V 10 A, siguiendo las instrucciones del fabricante y asegurándose de que estén debidamente conectados.
5. Organice los cables de manera ordenada para evitar enredos y asegúrese de que estén bien conectados a sus respectivos componentes.
6. Verifique que todos los componentes estén bien sujetos y que no haya cables sueltos que puedan interferir con el funcionamiento del generador eólico.

Mantenimiento del Chasis:

El mantenimiento regular del chasis es esencial para garantizar un funcionamiento seguro y eficiente de su generador eólico. A continuación, se detallan algunas pautas de mantenimiento:

1. Inspección Visual Regular: Realice inspecciones visuales regulares del chasis para identificar cualquier signo de desgaste, corrosión o daño en las paredes de chapa metálica, el esqueleto de acero o los componentes internos. Si se encuentra algún problema, repárelo o reemplace las partes afectadas de inmediato.
2. Limpieza: Mantenga el chasis limpio de polvo y suciedad que puedan obstruir el funcionamiento de los componentes internos. Limpie las superficies exteriores con un paño limpio y seco.
3. Verificación de Conexiones: Revise regularmente todas las conexiones eléctricas y cables para asegurarse de que estén bien conectados y en buen estado. Apriete cualquier conexión suelta o reemplace los cables dañados según sea necesario.
4. Verificación de Estabilidad: Asegúrese de que el chasis siga siendo estable y bien equilibrado. Verifique la integridad de las conexiones entre el esqueleto de acero y las paredes de chapa metálica.

Mecanismo de Transmisión de Potencia: Instrucciones de Armado

El mecanismo de transmisión de potencia es esencial para convertir la energía mecánica del generador en energía eléctrica utilizable. A continuación, se detallan las instrucciones para ensamblar el mecanismo de transmisión de potencia:

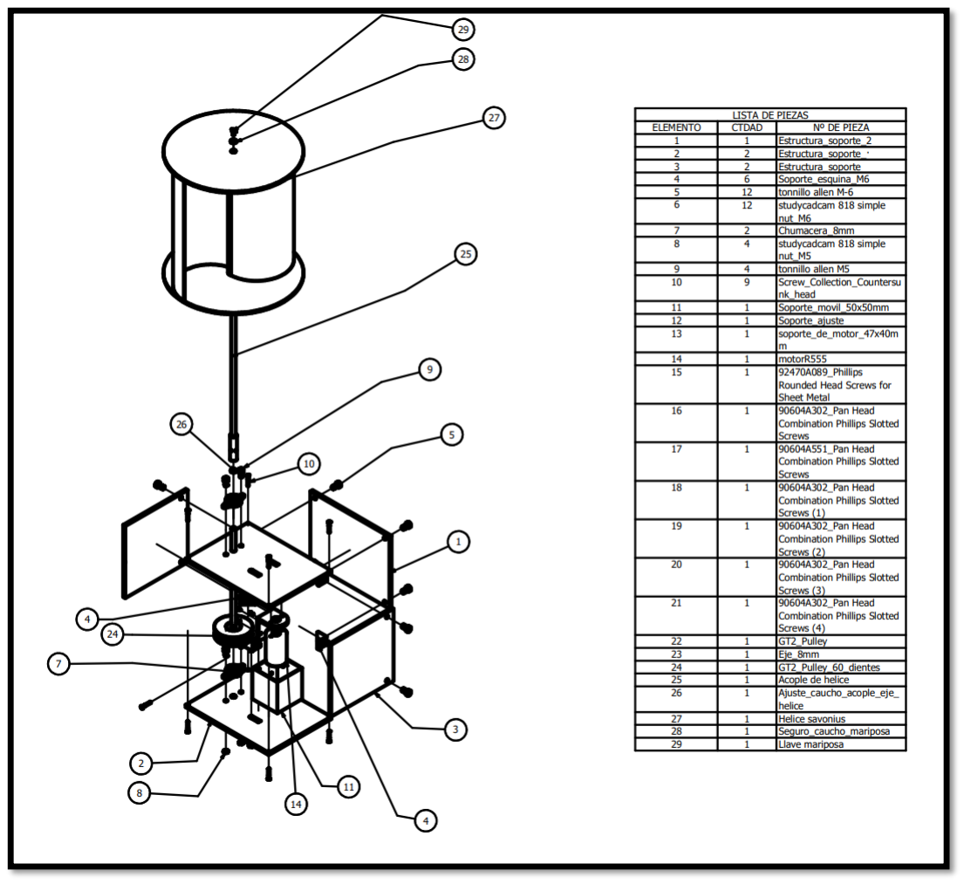
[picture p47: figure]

Materiales necesarios (lista de verificación):

- Poleas y correas adecuadas.
- Motor que funciona como generador.
- Polea loca.

- Herramientas básicas (llave, destornilladores, etc.) según sea necesario.
- Elementos adicionales específicos de su diseño (soportes, sujetadores, etc.).

Pasos de ensamblaje:

1. Coloque la polea loca en la ubicación deseada dentro del chasis, asegurándose de que esté firmemente sujeta al esqueleto de acero.
2. Monte el motor que funciona como generador en una posición adecuada dentro del chasis, de modo que la polea del motor se alinee con la polea loca.
3. Instale las poleas y correas adecuadas entre la polea del motor y la polea loca. Asegúrese de que las correas estén correctamente tensas para permitir una transmisión eficiente de la potencia.
4. Conecte el motor al sistema eléctrico del generador según las especificaciones del fabricante y asegúrese de que esté debidamente conectado al Arduino u otros componentes relevantes.
5. Verifique que el mecanismo de transmisión de potencia funcione correctamente al girar el motor a mano. Asegúrese de que las correas no estén demasiado apretadas ni demasiado flojas.

Mantenimiento del Mecanismo de Transmisión de Potencia:

El mantenimiento regular del mecanismo de transmisión de potencia es esencial para garantizar un funcionamiento eficiente de su generador eólico. A continuación, se detallan algunas pautas de mantenimiento:

1. Inspección Visual Regular: Realice inspecciones visuales regulares del mecanismo de transmisión de potencia para identificar cualquier signo de desgaste, daño o correas sueltas. Asegúrese de que todas las poleas estén alineadas correctamente.
2. Tensión de las Correas: Verifique la tensión de las correas regularmente. Asegúrese de que estén lo suficientemente ajustadas para garantizar una transmisión eficiente de la potencia, pero no demasiado apretadas para evitar el desgaste excesivo.

3. Lubricación: Si es necesario según las especificaciones del fabricante, aplique lubricante a las poleas y las correas para reducir la fricción y prolongar su vida útil.
4. Verificación de Conexiones Eléctricas: Revise las conexiones eléctricas del motor/generador para asegurarse de que estén bien conectadas y en buen estado.

Siguiendo estas instrucciones de armado y mantenimiento, podrá ensamblar y mantener eficazmente el chasis y el mecanismo de transmisión de potencia de su generador eólico. Esto garantizará un funcionamiento óptimo y seguro de su dispositivo en el tiempo.

Esquema general del módulo didáctico de generador eólico

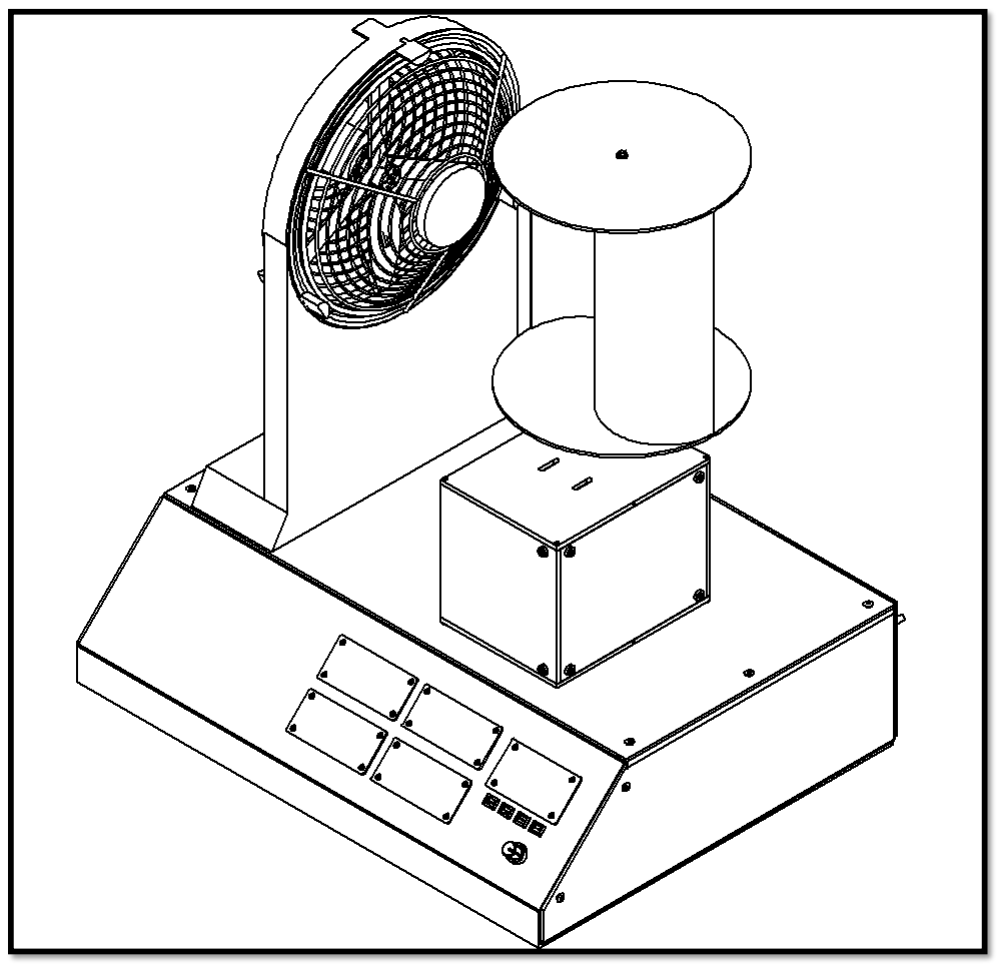
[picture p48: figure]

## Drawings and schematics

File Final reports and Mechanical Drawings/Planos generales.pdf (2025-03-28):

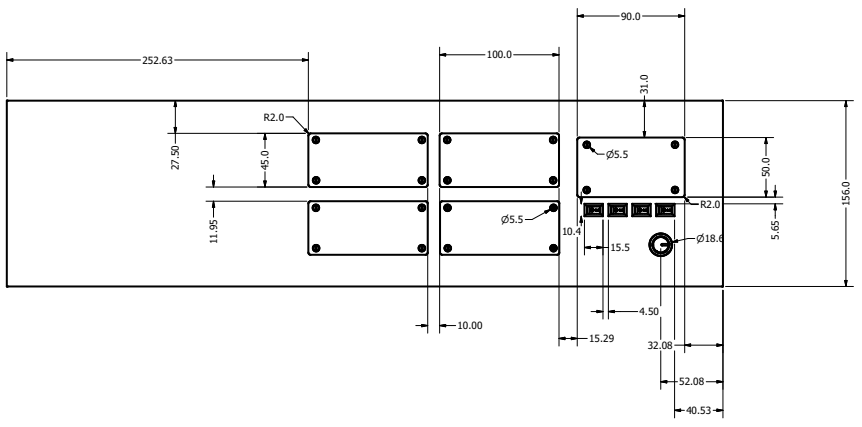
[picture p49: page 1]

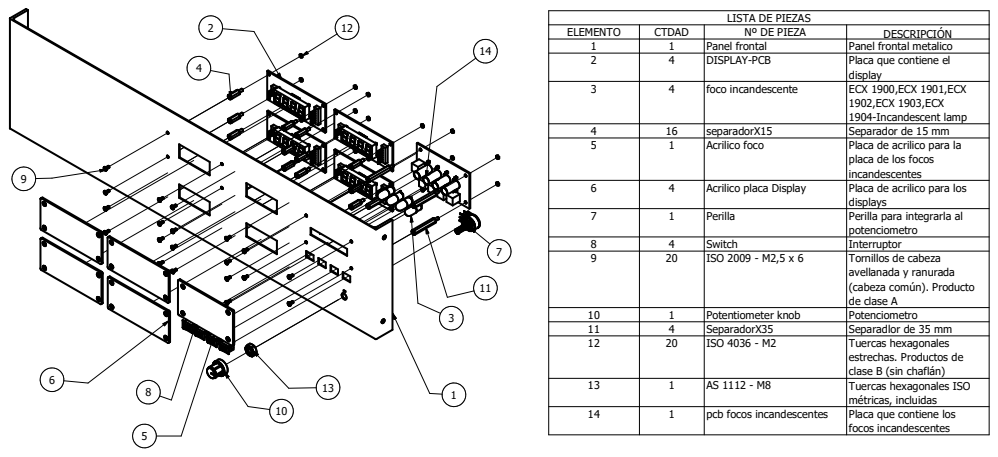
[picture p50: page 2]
ELEMENTO; CTDAD; Nº DE PIEZA; DESCRIPCIÓN 1; Panel frontal; Panel frontal metalico; display 2; DISPLAY-PCB; 1904-Incandescent lamp 3; foco incandescente 4; separadorX15; Separador de 15 mm; incandescentes 5; Acrilico foco; displays 6; Acrilico placa Display; potenciometro 7; Perilla 8; Switch; Interruptor; de clase A 9; ISO 2009 - M2,5 x 6; Potentiometer knob; Potenciometro; SeparadorX35; Separadlor de 35 mm; ISO 4036 - M2; pcb focos incandescentes 2

LISTA DE PIEZAS

Placa que contiene el

ECX 1900,ECX 1901,ECX
1902,ECX 1903,ECX

Placa de acrilico para la
placa de los focos

Placa de acrilico para los

Perilla para integrarla al

Tornillos de cabeza
avellanada y ranurada
(cabeza común). Producto

Tuercas hexagonales
estrechas. Productos de
clase B (sin chaflán)
Tuercas hexagonales ISO
métricas, incluidas
Placa que contiene los
focos incandescentes

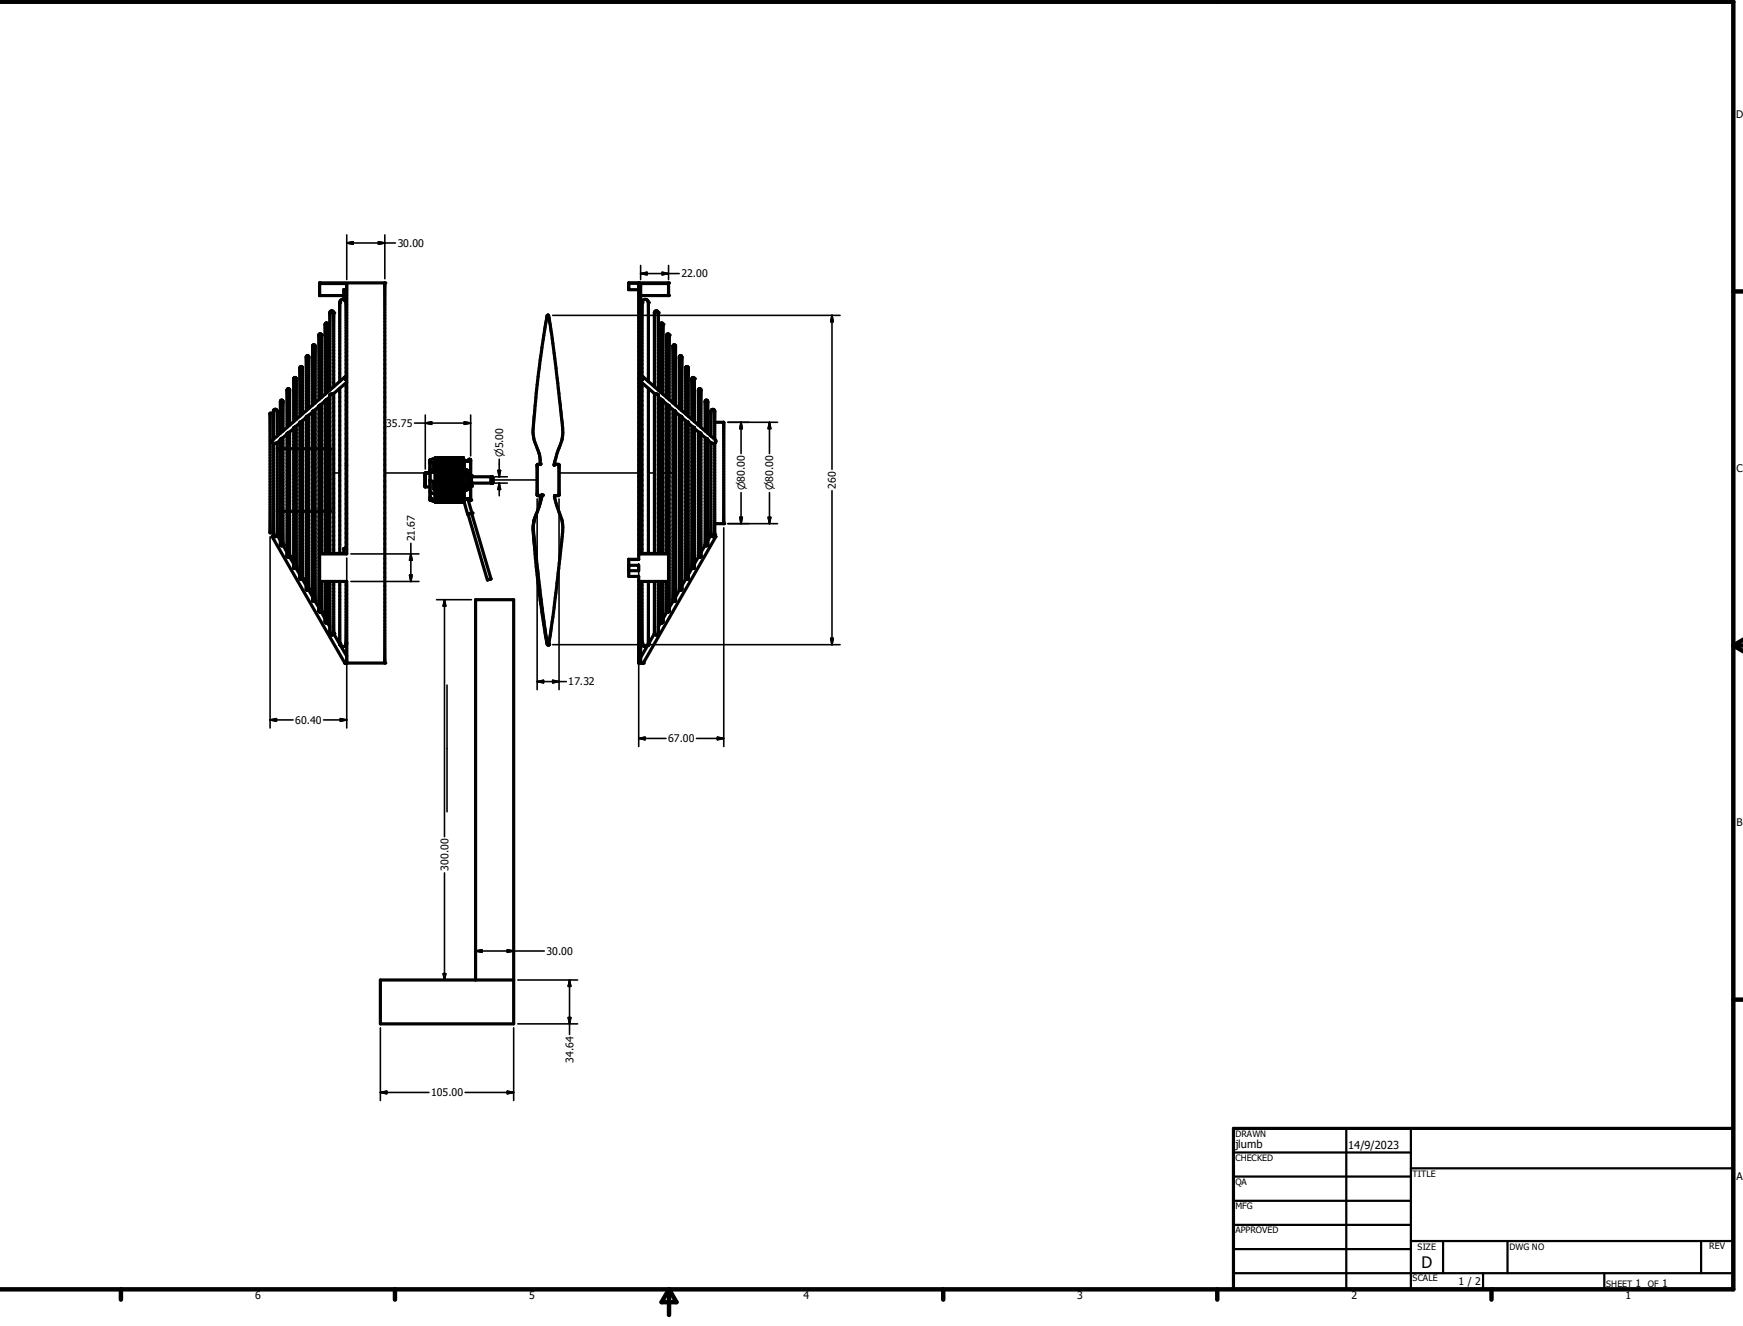
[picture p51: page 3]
APPROVED; jlumb; DWG NO; TITLE; SIZE D; SCALE; REV; 1 / 2 ²⁶⁰; 35.75 n⁸⁰.00 n⁸⁰.00

SHEET 1 OF 1 DRAWN
CHECKED QAMFG

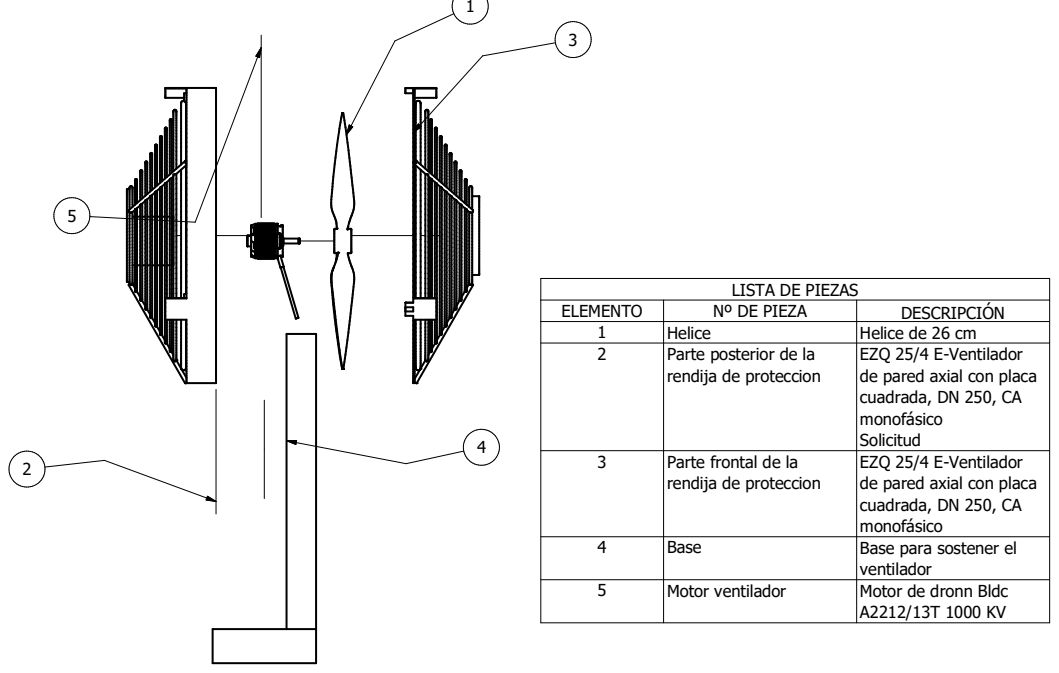
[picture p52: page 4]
ELEMENTO; Nº DE PIEZA; DESCRIPCIÓN; Helice; Helice de 26 cm; 4 Base; 5 Motor ventilador

LISTA DE PIEZAS

Parte posterior de la
rendija de proteccion

EZQ 25/4 E-Ventilador
de pared axial con placa
cuadrada, DN 250, CA
monofásico
Solicitud
Base para sostener el
ventilador
Motor de dronn Bldc

Parte frontal de la

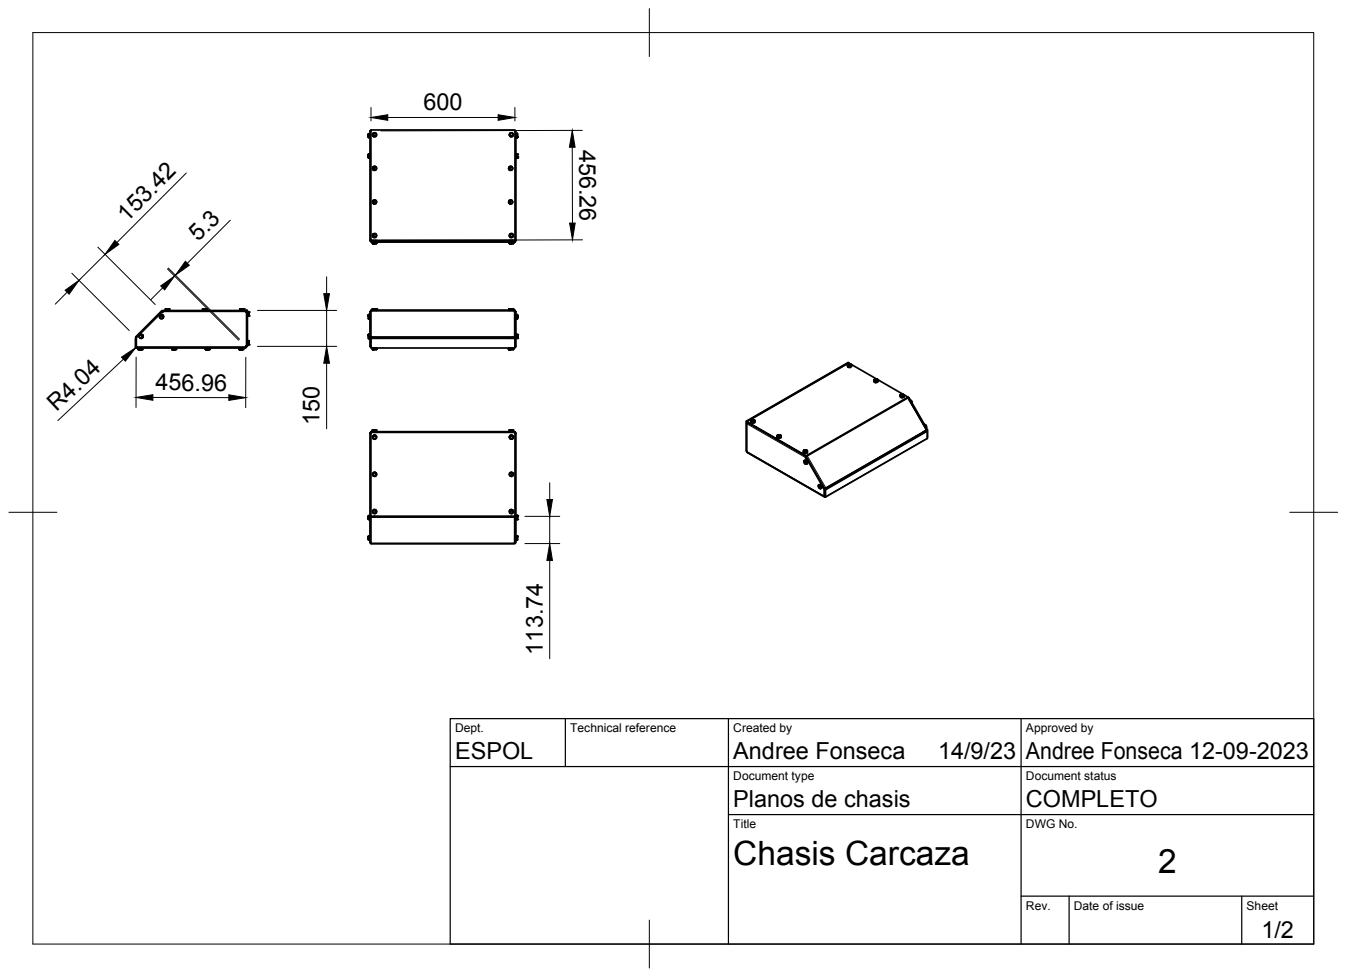
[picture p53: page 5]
Dept.; Technical reference; Created by; Approved by; Document type; Document status; Title; DWG No.; Rev.; Date of issue; Sheet; Planos de chasis; COMPLETO; Chasis Carcaza; ESPOL; Andree Fonseca

Dept. | Technical reference | Created by | Approved by
Document type | Document status
Title | DWG No.
Rev. | Date of issue | Sheet
Planos de chasis | COMPLETO
14/9/23 | 12-09-2023
Chasis Carcaza | 2
ESPOL | Andree Fonseca | Andree Fonseca

Lista de piezas
elem
ento | ctd | número de pieza | descripción | material
1 | 1 | Abajo | | Acero
2 | 1 | Derecha | | Acero
3 | 1 | Izquierda | | Acero
4 | 1 | Pieza1 | | Acero
5 | 1 | Arriba | | Acero
6 | 22 | 4017A410020109(
| | 1).stp | | Acero
7 | 1 | Frente | | Acero

30 | 31 | 29

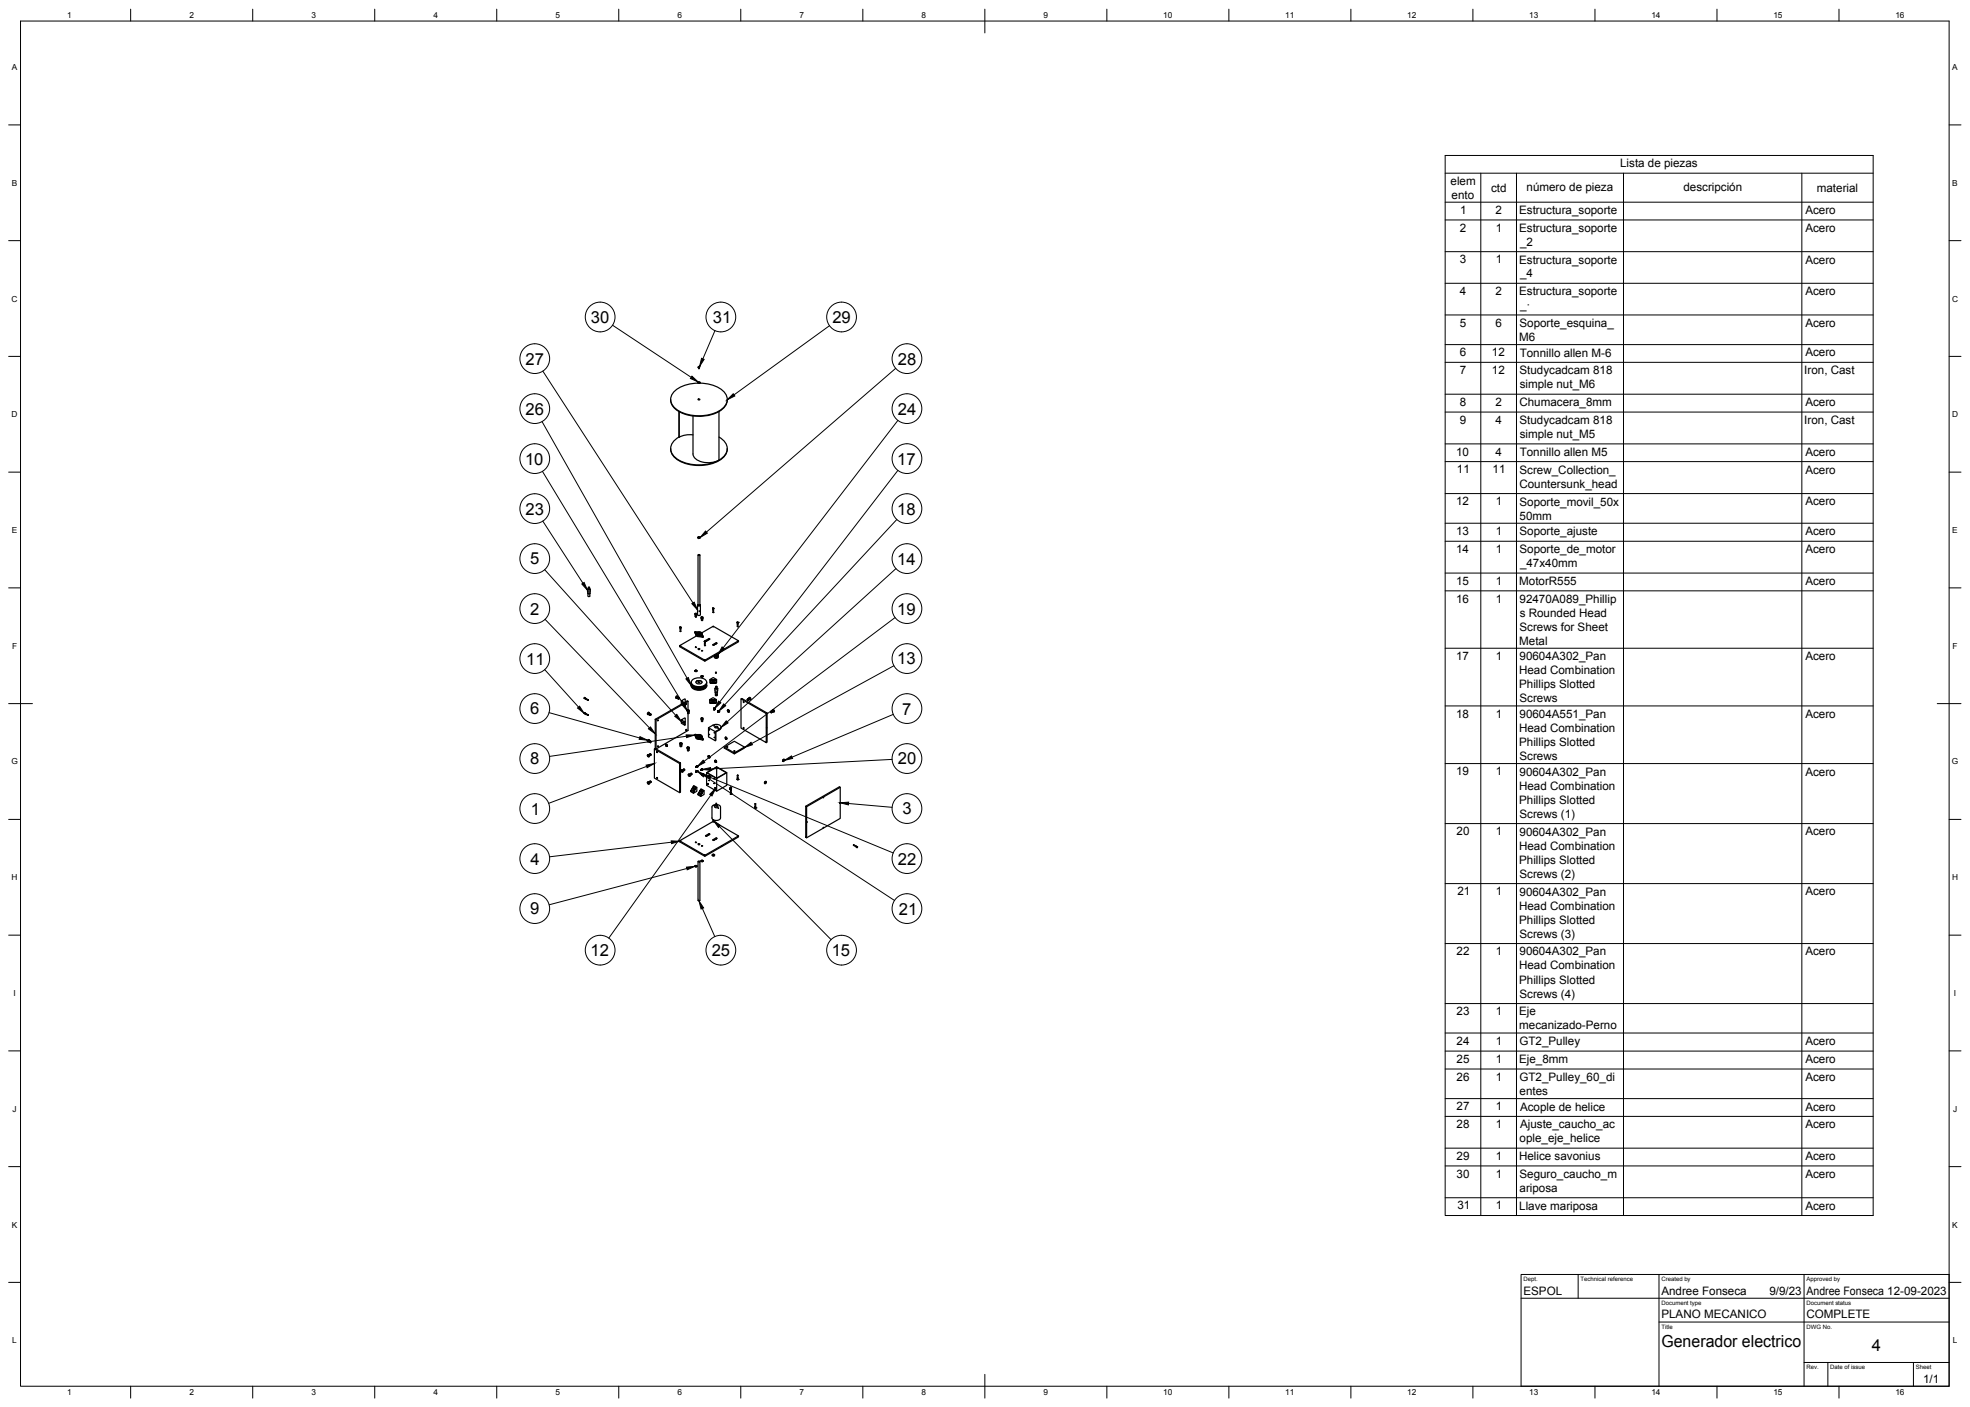
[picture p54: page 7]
Dept.; Technical reference; Created by; Approved by; Document type; Document status; Title; DWG No.; Rev.; Date of issue; Sheet; PLANO MECANICO; COMPLETE; Generador electrico; ESPOL; Andree Fonseca; elem ento; ctd; número de pieza; descripción; material 1; Estructura_soporte; Acero 2; Acero 3; Acero 4; Acero 5; Soporte_esquina_; Acero 6; Tonnillo allen M-6; Acero 7; Studycadcam 818; simple nut_M6; Iron, Cast 8; Chumacera_8mm; Acero 9; simple nut_M5; Iron, Cast; Tonnillo allen M5; Acero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

Lista de piezas

s Rounded Head
Screws for Sheet
Metal

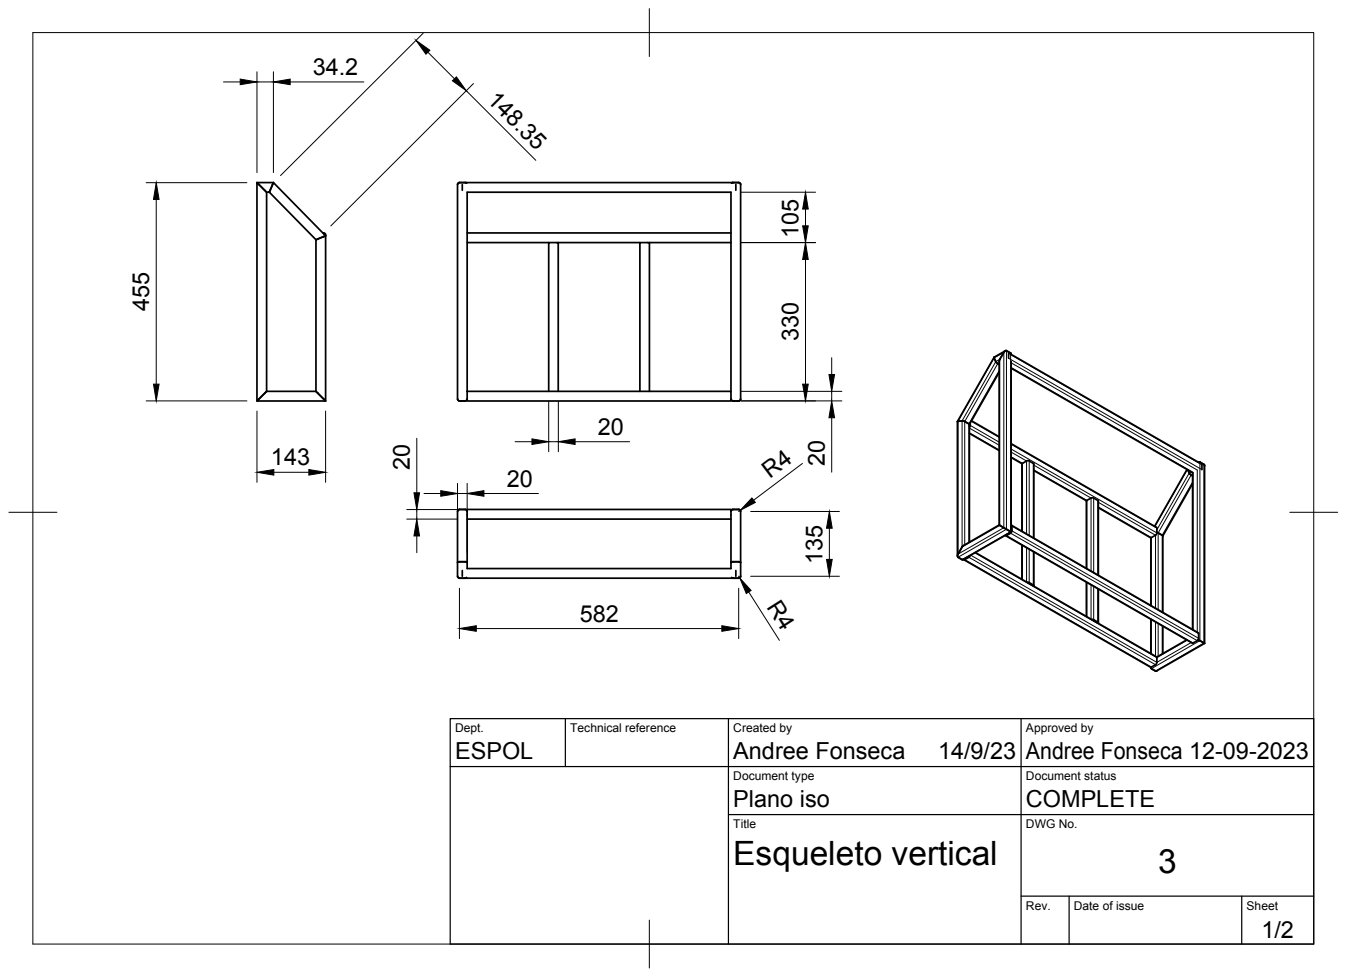
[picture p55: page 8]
Dept.; Technical reference; Created by; Approved by; Document type; Document status; Title; DWG No.; Rev.; Date of issue; Sheet; Plano iso; COMPLETE; Esqueleto vertical; ESPOL; Andree Fonseca

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

14/9/23

## Esqueleto vertical

Andree Fonseca

Lista de piezas
elem
ento | ctd | número de pieza | descripción | material
1 | 1 | Esqueleto vertical | | Generic

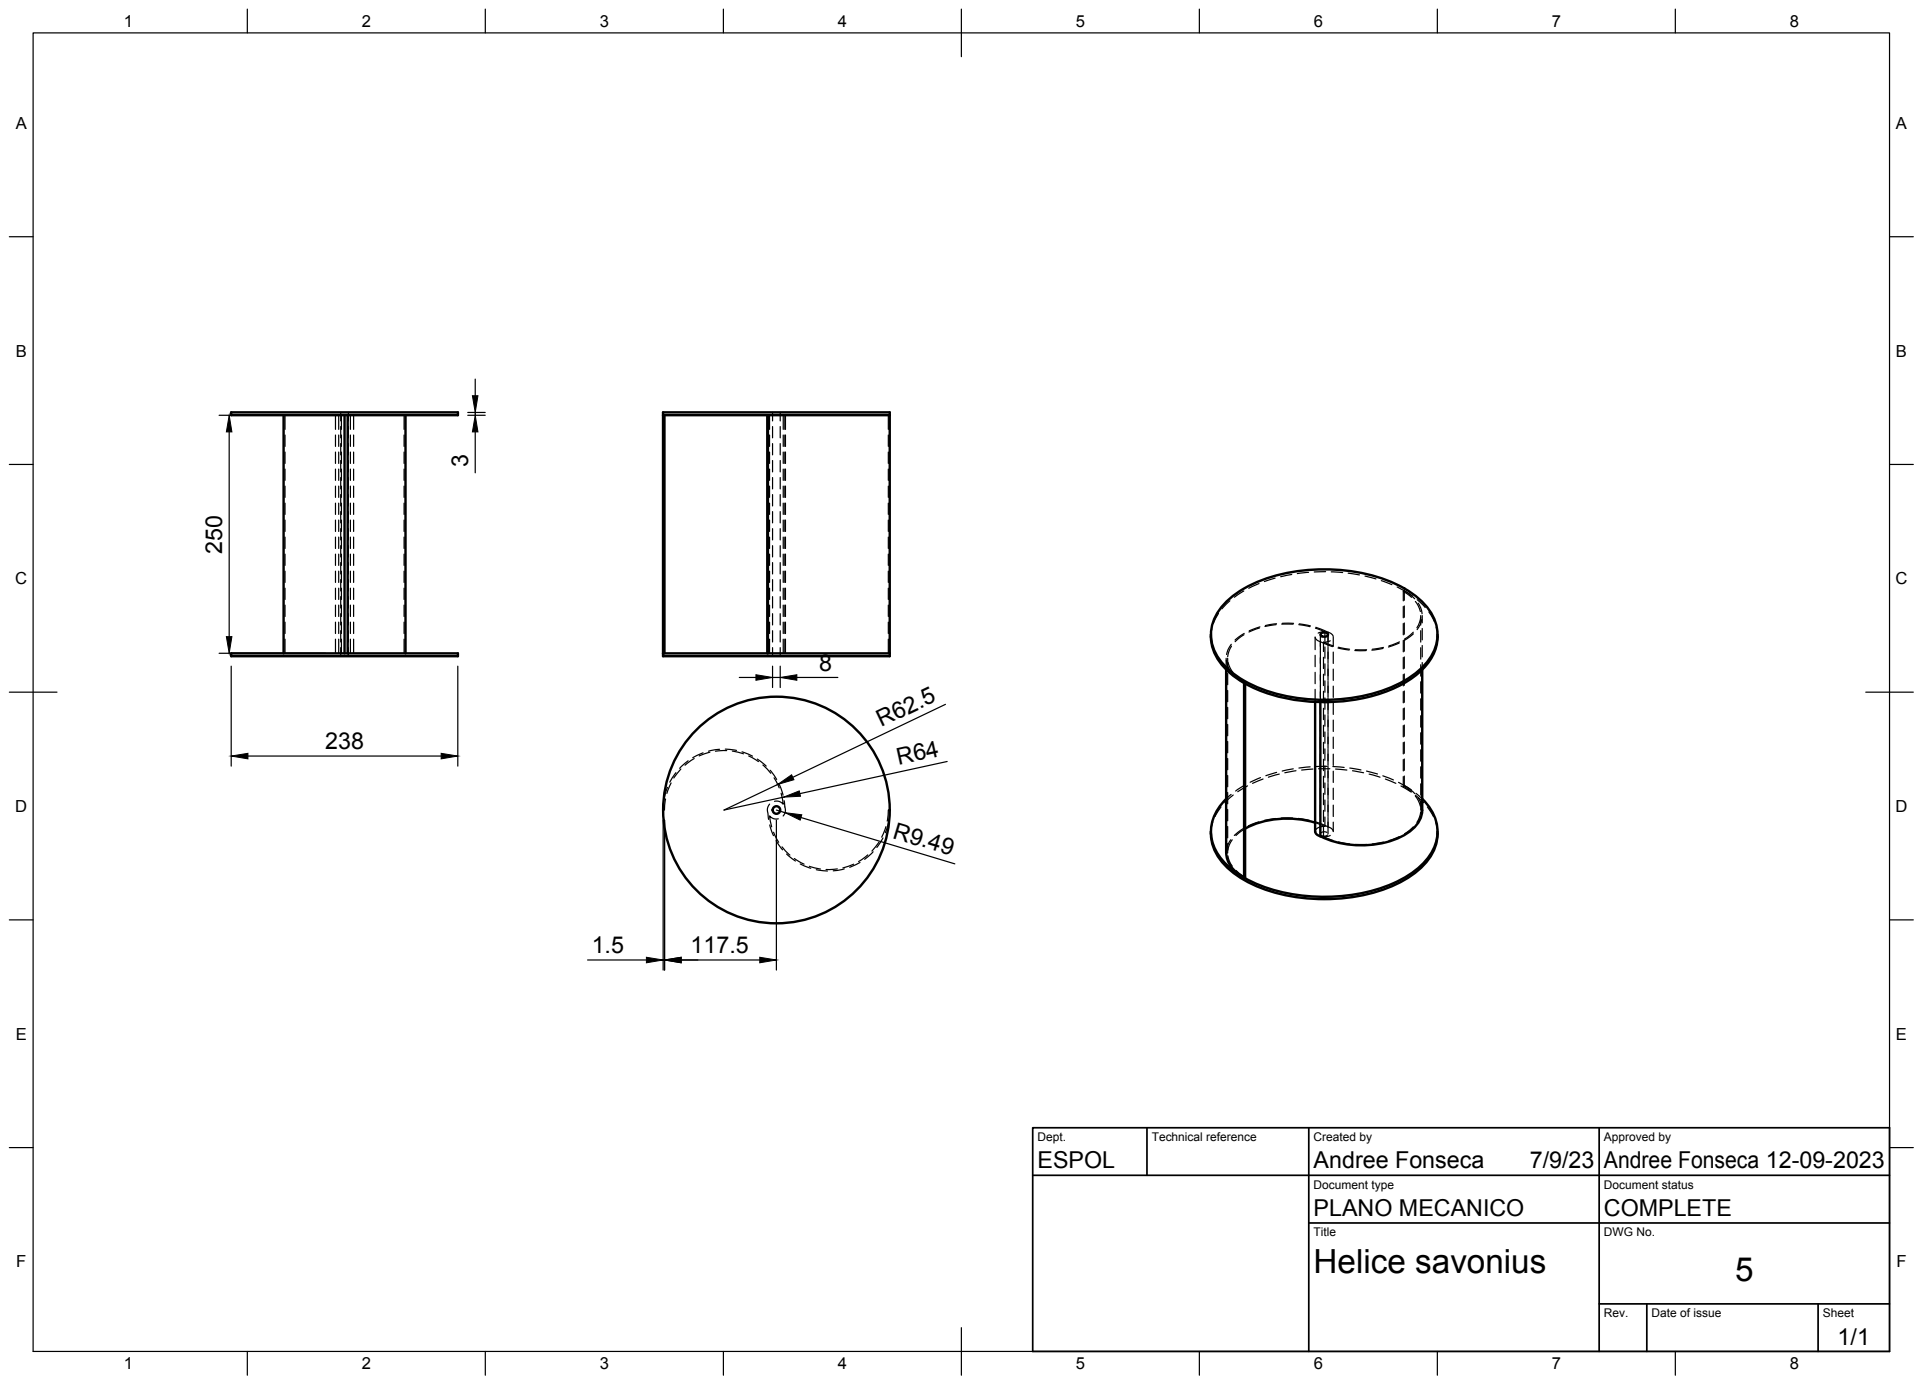
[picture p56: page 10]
Dept.; Technical reference; Created by; Approved by; Document type; Document status; Title; DWG No.; Rev.; Date of issue; Sheet; PLANO MECANICO; COMPLETE; Helice savonius; ESPOL; Andree Fonseca; 238 ²⁵⁰

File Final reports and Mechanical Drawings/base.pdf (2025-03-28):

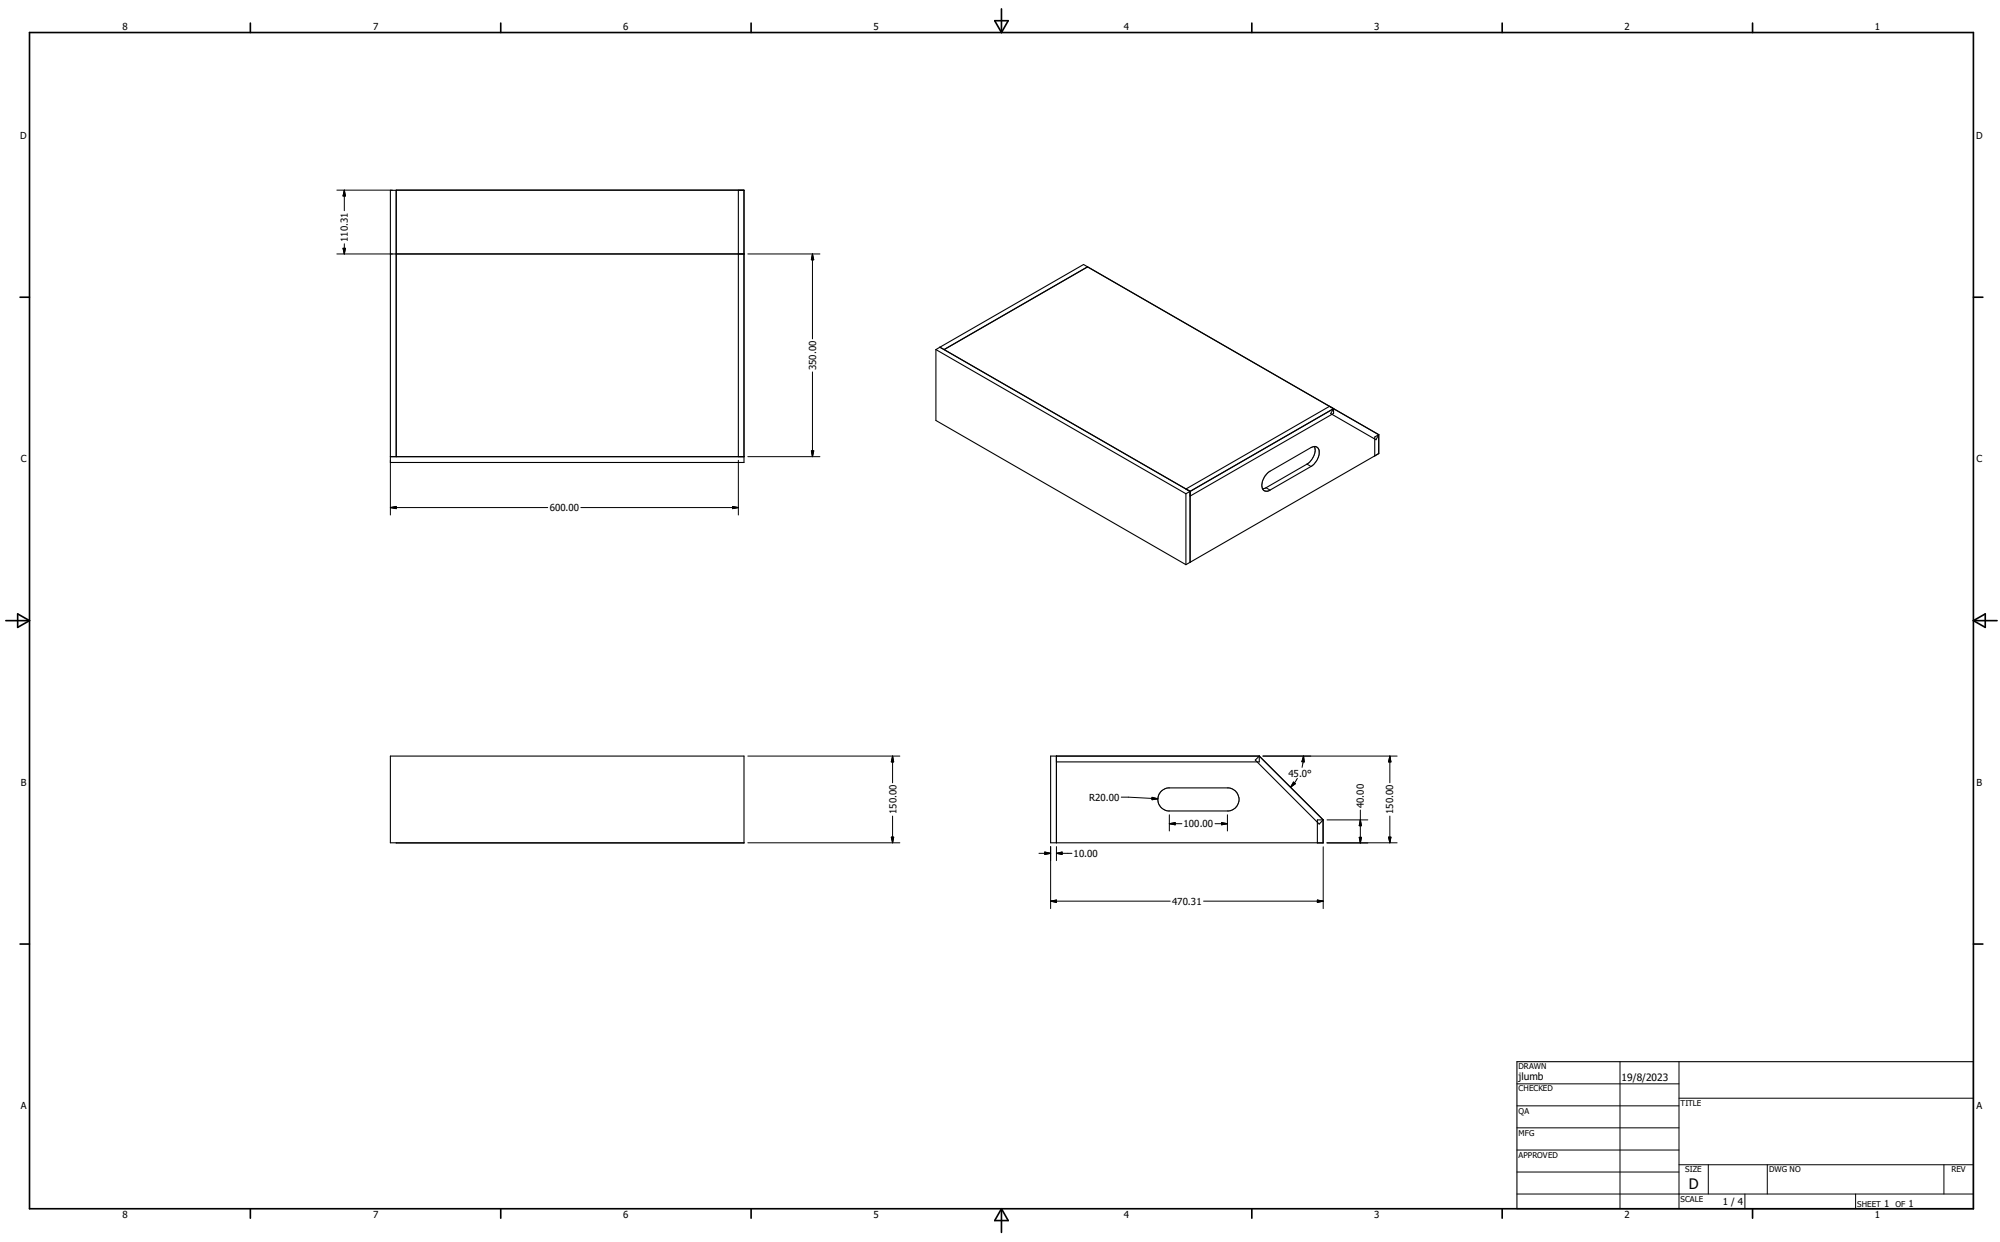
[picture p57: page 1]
jlumb; DWG NO; TITLE

SHEET 1 OF 1 DRAWN
CHECKED QA MFG

APPROVED

SCALE SIZE D | | REV

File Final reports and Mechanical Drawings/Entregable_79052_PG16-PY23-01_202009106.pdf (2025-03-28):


Dept. ESPOL | Technical reference | Created by Andree Fonseca 14/9/23 | Approved by Andree Fonseca 12-09-2023

Document type Planos de chasis | Document status COMPLETO

Title Chasis Carcaza | DWG No. 2

Rev. | Date of issue | Sheet 1/2

Dept. ESPOL | Technical reference | Created by Andree Fonseca 14/9/23 | Approved by Andree Fonseca 12-09-2023
| | Document type Planos de chasis | Document status COMPLETO
| | Title Chasis Carcaza | DWG No. 2
Rev. | Date of issue | Sheet 2/2

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

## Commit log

2025-03-28 commit inicial
    [ANSI B18.3.1M - M2x0,4 x 30(1).ipt]
2025-03-28 Files uploaded
    [ANSI B18.3.1M - M2x0,4 x 30(1).ipt]
